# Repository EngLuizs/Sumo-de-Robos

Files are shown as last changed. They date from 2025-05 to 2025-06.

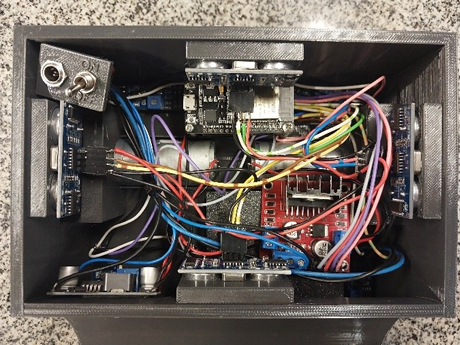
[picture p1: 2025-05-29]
Hardware - Robô Sumô .png

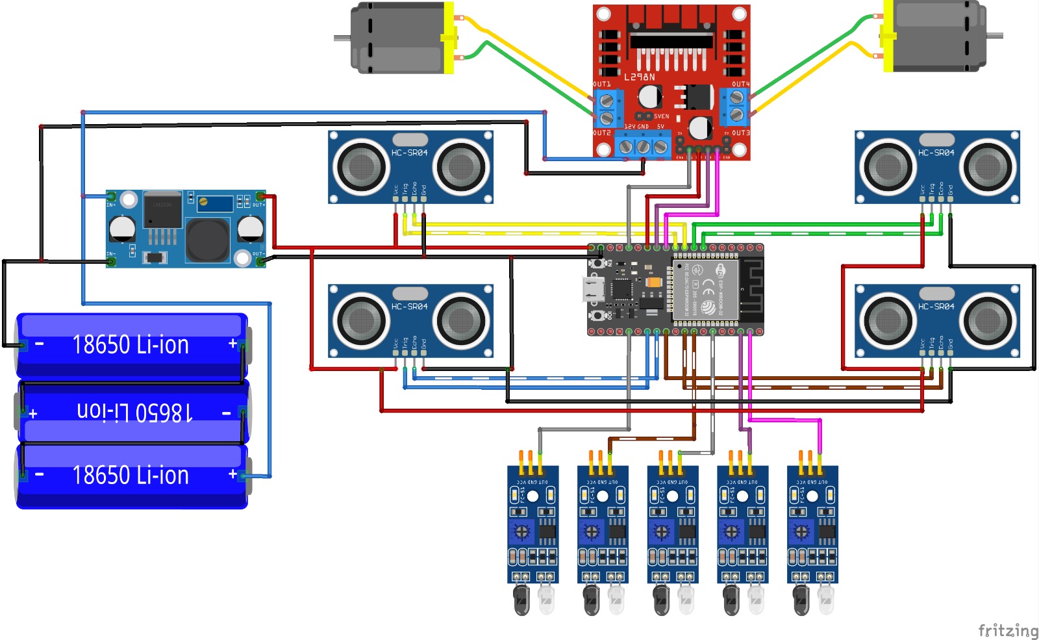
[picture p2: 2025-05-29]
Esquemático - Robô Sumô .jpg

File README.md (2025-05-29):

# 🤖 Robô Sumô - EngRobots

Este projeto apresenta um robô sumô autônomo controlado por ESP32, equipado com sensores IR e ultrassônicos, e capaz de receber comandos via Bluetooth. Desenvolvido para competições de robótica, o robô detecta bordas da arena e localiza o oponente para atacá-lo ou se reposicionar estrategicamente.

## 🚀 Funcionalidades

- Detecção da borda da arena com 5 sensores infravermelhos (IR)
- Detecção de oponente com 4 sensores ultrassônicos (frente, trás, esquerda, direita)
- Controle dos motores por ponte H (duas rodas motrizes)
- Conexão Bluetooth para controle remoto
- Comportamento autônomo de ataque e evasão
- Código modular com funções para sensores e movimentos

## 🧩 Componentes Utilizados

- ESP32
- 4 Sensores Ultrassônicos HC-SR04
- 5 Sensores Infravermelhos (IR)
- Ponte H (L298N ou similar)
- 2 Motores DC com redução (ex: N20 1000RPM)
- Fonte de alimentação (pack de baterias)
- Módulo Bluetooth (via ESP32 integrado)
- Estrutura impressa em 3D

## 📐 Pinagem

| Componente | Pinos ESP32 |
|---|---|
| Ultrassônico Frente (Trigger, Echo) | 26, 25 |
| Ultrassônico Trás | 33, 32 |
| Ultrassônico Direito| 4, 16 |
| Ultrassônico Esquerdo| 17, 18 |
| IR Frente Dir (IRFD) | 19 |
| IR Frente Centro (IRFC) | 21 |
| IR Frente Esq (IRFE) | 22 |
| IR Trás Dir (IRTD)  | 35 |
| IR Trás Esq (IRTE)  | 34 |
| Ponte H (Motor 1) | 23, 13 |
| Ponte H (Motor 2) | 12, 27 |

## 📲 Comandos Bluetooth

O robô aceita comandos via aplicativo Bluetooth ou monitor serial Bluetooth (ex: Serial Bluetooth Terminal):

- **`L`**: Inicia o modo de luta (autônomo)
- **`D`**: Interrompe o modo de luta

Nome do dispositivo Bluetooth: **EngRobots**

## 🧠 Lógica de Decisão

- Se sensores IR detectam borda → realiza manobra de recuo e reposicionamento
- Se sensores ultrassônicos detectam oponente à frente → avança
- Se oponente está nos lados → gira em direção ao oponente
- Se não detecta nada → para os motores

## 🎮 Controle de Movimento

- `move_pra_frente()`
- `dar_re()`
- `virar_pra_direita()`
- `virar_pra_esquerda()`
- `pararMotores()`

## 🛠️ Como Usar

1. Faça upload do código para o ESP32 usando o Arduino IDE.
2. Conecte os sensores e motores conforme a pinagem.
3. Alimente o robô com bateria adequada.
4. Emparelhe o Bluetooth com seu celular/computador.
5. Envie o comando **`L`** para iniciar a luta.

## 📎 Licença

Este projeto é de uso educacional e livre para modificações.

---

Desenvolvido por **EngRobots** 🤖⚡

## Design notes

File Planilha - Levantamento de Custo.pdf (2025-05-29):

Componentes | Valor | Quantidade | Total
ESP32 | R$ 38,97 | 1 | R$ 38,97
Motor DC 12V 500RPM | R$ 59,90 | 2 | R$ 119,80
Ponte H L298N | R$ 12,99 | 1 | R$ 12,99
Sensor TCRT5000 | R$ 7,19 | 5 | R$ 35,95
Baterias Li-íon 18650 | R$ 8,25 | 4 | R$ 33,00
Sensor Ultrassonico HC-SR04 | R$ 9,96 | 5 | R$ 49,80
Pneu 50mm - NEO | R$ 8,90 | 2 | R$ 17,80
Fonte Chaveada | R$ 14,90 | 1 | R$ 14,90
Regulador de Tensão LM256 3A | R$ 17,99 | 1 | R$ 17,99
Módulo Carregador 3s 20A | R$ 15,90 | 1 | R$ 15,90
Filamento PETG Voolt3D 1,75mm - Cor Grafite | R$ 79,90 | 1 | R$ 79,90
Custo Total: | R$ 437,00

### Planilha de Levantamento de Custo - Projeto Robo Sumo Grupo EngRobots

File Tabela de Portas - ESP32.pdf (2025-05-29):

UF | ESP32 PORT | WIRE COLOR | IRFD | ESP32 PORT | WIRE COLOR | PH1 | ESP32 PORT | WIRE COLOR
Vcc | 5V | VERMELHO | Vcc | 3V3 | BRANCO | IN1 | GPIO23 | CINZA
Trig | GPIO26 | AMARELO | GND | 0V | PRETO | IN2 | GPIO13 | VERMELHO
Echo GPIO25 | BRANCO/AMARELO | D0 | GPIO19 | MARROM/VERDE | IN3 | GPIO12 | ROXO
GND 0V | PRETO | IN4 | GPIO27 | ROSA
UT | ESP32 PORT | WIRE COLOR | IRFC | ESP32 PORT | WIRE COLOR | BUZZER | ESP32 PORT | WIRE COLOR
Vcc | 5V | VERMELHO | Vcc | 3V3 | BRANCO | Vcc | 3V3 | -
Trig | GPIO33 | VERDE | GND | 0V | PRETO | GND | 0V | -
Echo GPIO32 | BRANCO/VERDE | D0 | GPIO21 | CINZA/ROSA | D0 | GPIO2 | -
GND 0V | PRETO
UD | ESP32 PORT | WIRE COLOR | IRFE | ESP32 PORT | WIRE COLOR
Vcc | 5V | VERMELHO | Vcc | 3V3 | BRANCO
Trig | GPIO4 | AZUL | GND | 0V | PRETO
Echo GPIO16 | VERMELHO/AZUL | D0 | GPIO22 | ROXO
GND 0V | PRETO
UE | ESP32 PORT | WIRE COLOR | IRTD | ESP32 PORT | WIRE COLOR
Vcc | 5V | VERMELHO | Vcc | 3V3 | BRANCO
Trig | GPIO17 | MARROM | GND | 0V | PRETO
Echo GPIO18 | AMARELO/MARROM | D0 | GPIO35 | ROSA
GND 0V | PRETO
| | | IRTE | ESP32 PORT | WIRE COLOR
| | | Vcc | 3V3 | BRANCO
| | | GND | 0V | PRETO
| | | D0 | GPIO34 | CINZA

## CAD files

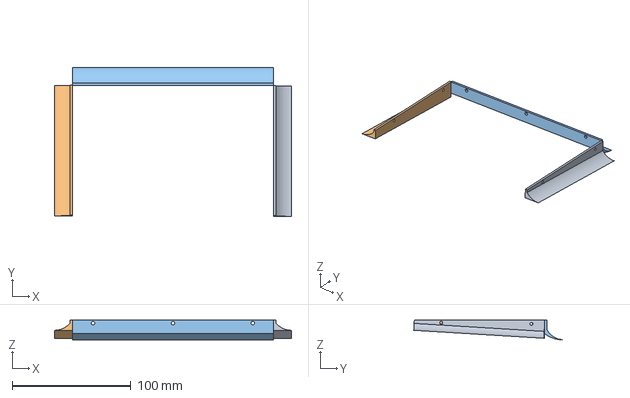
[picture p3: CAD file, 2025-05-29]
3D - Rampas Laterais.step
200.0 x 125.4 x 16.7 mm
Rampa Lateral
Rampa Traseira

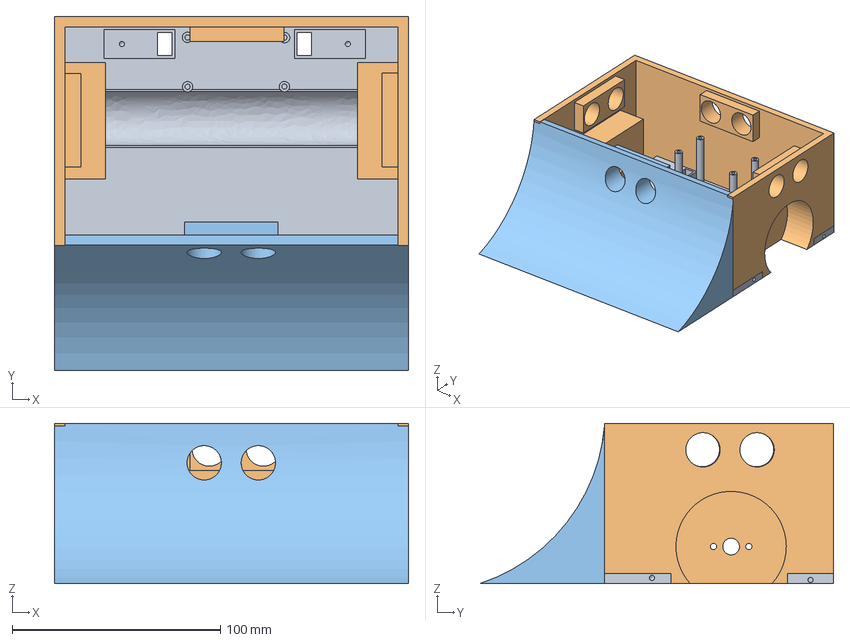
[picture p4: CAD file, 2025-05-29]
3D - Carcaça.step
170.0 x 170.0 x 77.0 mm
Base
Parede
Rampa Frontal

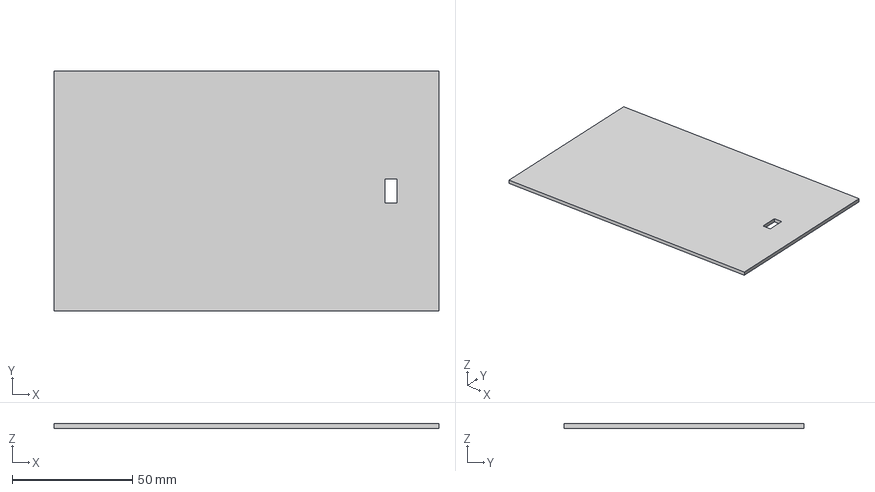
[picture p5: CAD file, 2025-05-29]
3D - Tampa.step
160.0 x 99.8 x 2.00 mm

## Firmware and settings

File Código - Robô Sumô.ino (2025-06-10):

/*******************************************************************************************************************************
Autor............: Equipe Eng Robots
Disciplina.......: APS
Data.............: 06/2025
*******************************************************************************************************************************/

// INCLUINDO AS BIBLIOTECAS
#include "Ultrasonic.h"
#include "BluetoothSerial.h"

// FUNÇÕES UTILIZADAS
  void leiturasIR();
  void estadoIR();
  void estadoUltra(); // AGORA RETORNA UM VALOR
  void leiturasUltra();
  void virar_pra_esquerda();
  void virar_pra_direita();
  void move_pra_frente();
  void dar_re();
  void pararMotores();
  void virar_180();
  void buzzer_on();
  void buzzer_off();

// DEFININDO PINOS SENSOR ULTRASSÔNICOS
  HC_SR04 SensorUF(26,25);  //(Trigger, Echo)
  HC_SR04 SensorUT(33,32);
  HC_SR04 SensorUD(4,16);
  HC_SR04 SensorUE(17,18);

// DEFININDO PINOS PONTE H
  #define anti_horarioE 23
  #define horarioE 13
  #define anti_horarioD 12
  #define horarioD 27
  #define PINO_BUZZER 2

// DEFININDO PINOS SENSORES IR
  #define IRFD 19
  #define IRFC 21
  #define IRFE 22
  #define IRTD 35
  #define IRTE 34

// DEFININDO COR LIDA PELO SENSOR IR
  #define branco 0
  #define preto 1

// DEFININDO AS VELOCIDADES
  #define velocidade 255
  #define velocidade2 210
  #define velocidade3 75
  #define velocidade4 50

// DISTÂNCIA MAXIMA DE DETECÇÃO
  #define distancia 80

//CONFIGURANDO A COMUNICAÇÃO BLUETOOTH 
  BluetoothSerial serialBLE;

//ADICIONANDO VARIAVEIS DO BLUETOOTH 
  char dados;
  bool conexao;

// VARIÁVEIS
  int estadoIRFD, estadoIRFC, estadoIRFE, estadoIRTD, estadoIRTE;
  int estadoUF, estadoUT, estadoUD, estadoUE;

void setup() {
  Serial.begin(9600);
  serialBLE.begin("EngRobots");

// CONFIURANDO MOTORES E VELOCIDADES
  pinMode(anti_horarioE, OUTPUT);
  pinMode(horarioE, OUTPUT);
  pinMode(anti_horarioD, OUTPUT);
  pinMode(horarioD, OUTPUT);
  pinMode(velocidade, OUTPUT);
  pinMode(velocidade2, OUTPUT);
  pinMode(velocidade3, OUTPUT);
  pinMode(velocidade4, OUTPUT);

// CONFIGURANDO IR's COMO ENTRADA
  pinMode(IRFD, INPUT);
  pinMode(IRFC, INPUT);
  pinMode(IRFE, INPUT);
  pinMode(IRTD, INPUT);
  pinMode(IRTE, INPUT);

// CONFIGURANDO BUZZER E INICIANDO DESLIGADO
  pinMode(PINO_BUZZER, OUTPUT);
  digitalWrite(PINO_BUZZER, LOW);

  // FORÇANDO A INICIALIZAÇÃO COM OS MOTORES DESLIGADOS
  pararMotores();
}

void loop() 
{

  leiturasUltra(); //LENDO ULTRA
  estadoUltra();   //AÇÃO DO ULTRA
  leiturasIR();    //LENDO IR
  estadoIR();      //AÇÃO IR

//COMANDOS BLUETOOTH
    conexao = serialBLE.available();
    if (conexao == true) // SE A CONEXÃO FOR VERDADEIRA, SE FAZ A LEITURA DOS DADOS ENVIADOS
    {
      dados = serialBLE.read();
      if (dados == 'D')  // SE DADOS FOR IGUAL A "D" DESIGA O ROBÔ
      {
        while (true)
        {
          pararMotores();
          if (serialBLE.available())
          {
            dados = serialBLE.read();  // SE DADOS FOR IGUAL A "L" ELE LIGA O ROBÔ DEPOIS DE DESLIGADO
            if (dados == 'L')
            {
              break; // Sai do while
            }
          }
        }
      }
    }
}


// LEITURA DOS SENSORES IR
  void leiturasIR() {
    estadoIRFD = digitalRead(IRFD);
    estadoIRFC = digitalRead(IRFC);
    estadoIRFE = digitalRead(IRFE);
    estadoIRTD = digitalRead(IRTD);
    estadoIRTE = digitalRead(IRTE);
  }

// AÇÕES COM BASE NOS SENSORES IR
  void estadoIR() {
    if ((estadoIRFD == branco) || (estadoIRFC == branco) || (estadoIRFE == branco)) { 
      dar_re();
      delay(250);
      virar_180();
    }

    if ((estadoIRTD == branco) || (estadoIRTE == branco)) {
      move_pra_frente();
    } 
  }

// AÇÕES COM BASE NOS ULTRASSONICOS
  void estadoUltra() {

    if (estadoUF <= distancia) 
    {
      move_pra_frente();
      buzzer_on();
      delay(150);
      buzzer_off();
    } 
      
    else if (estadoUD <= distancia)
    {
      virar_pra_direita();
    } 
      
    else if (estadoUE <= distancia) {
      virar_pra_esquerda();
    } 
      
    else if (estadoUT <= distancia)
    {
      virar_180();
    } 
      
    else 
    {
      move_pra_frente_lento();
    }
  }

// LEITURA ULTRASSÔNICO
  void leiturasUltra() 
  {
    estadoUF = SensorUF.distance();
    estadoUT = SensorUT.distance();
    estadoUD = SensorUD.distance();
    estadoUE = SensorUE.distance();
  }

// CONTROLE DOS MOTORES
  void move_pra_frente() 
  {
    analogWrite(anti_horarioE, velocidade);
    analogWrite(horarioE, 0);
    analogWrite(anti_horarioD, velocidade);
    analogWrite(horarioD, 0);
  }

  void move_pra_frente_lento() 
  {
    analogWrite(anti_horarioE, velocidade4);
    analogWrite(horarioE, 0);
    analogWrite(anti_horarioD, velocidade4);
    analogWrite(horarioD, 0);
  }

  void dar_re() 
  {
    analogWrite(anti_horarioE, 0);
    analogWrite(horarioE, velocidade);
    analogWrite(anti_horarioD, 0);
    analogWrite(horarioD, velocidade);
  }

  void virar_pra_esquerda() 
  {
    analogWrite(anti_horarioE, 0);
    analogWrite(horarioE, velocidade3);
    analogWrite(anti_horarioD, velocidade2);
    analogWrite(horarioD, 0);
  }

  void virar_pra_direita() 
  {
    analogWrite(anti_horarioE, velocidade2);
    analogWrite(horarioE, 0);
    analogWrite(anti_horarioD, 0);
    analogWrite(horarioD, velocidade3);
  }

  void virar_180() 
  {
    analogWrite(anti_horarioE, 0);
    analogWrite(horarioE, velocidade2);
    analogWrite(anti_horarioD, velocidade);
    analogWrite(horarioD, 0);
  }

  void pararMotores() 
  {
    analogWrite(anti_horarioE, 0);
    analogWrite(horarioE, 0);
    analogWrite(anti_horarioD, 0);
    analogWrite(horarioD, 0);
  }

// BUZZER
  void buzzer_on() 
  {
    digitalWrite(PINO_BUZZER, HIGH);
  }

  void buzzer_off() 
  {
    digitalWrite(PINO_BUZZER, LOW);
  }
